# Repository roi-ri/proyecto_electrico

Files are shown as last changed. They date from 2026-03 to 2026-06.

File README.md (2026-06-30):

# Proyecto Eléctrico - Ciclador de Baterías

Repositorio integral del proyecto de diseño, construcción y validación de un
ciclador de baterías de propósito múltiple. El proyecto reúne el hardware de
potencia y medición, el firmware de control, el protocolo de comunicación y una
aplicación de escritorio para operar pruebas, visualizar telemetría y exportar
resultados.

## Descripción general

El sistema está orientado a ejecutar pruebas controladas de carga, descarga y
ciclado sobre baterías. La arquitectura combina una PCB dedicada, un ESP32 como
unidad de control y adquisición, sensores de corriente y tensión, y la
aplicación `batView` para supervisar el proceso desde una computadora.

Los objetivos principales del repositorio son:

- Centralizar la documentación técnica y administrativa del proyecto.
- Mantener el diseño eléctrico y los archivos de fabricación de la PCB.
- Versionar el firmware encargado del control y la comunicación.
- Desarrollar la aplicación de escritorio para operación, monitoreo y
  exportación de datos.
- Conservar cronogramas, bitácoras y propuestas como evidencia del avance.

## Componentes del sistema

| Componente | Ubicación | Descripción |
|---|---|---|
| Aplicación de escritorio | `batView/` | Interfaz en C++/wxWidgets para controlar pruebas vía USB/UART, graficar telemetría y exportar resultados. |
| Firmware/control | `code/` | Código en C para control PI, monitoreo de carga/descarga, límites de tensión y comunicación con la PC. |
| PCB | `PCB/` | Proyecto KiCad con esquemático, layout, huellas, símbolos, modelos 3D, salidas e imágenes del diseño. |
| Propuesta | `propuesta/` | Descripción inicial del ciclador, diagramas y documentos de diseño por área. |
| Cronograma | `cronograma/` | Plan de trabajo semanal del proyecto. |
| Bitácoras | `bitácora/` | Registro individual de avances, decisiones y actividades. |

## Estructura del repositorio

```text
proyecto_electrico/
|
├── README.md                         documentación principal del repositorio
├── LICENSE                           licencia MIT del proyecto
├── .gitignore                        reglas generales de archivos ignorados
├── .gitmodules                       submódulos utilizados por el repositorio
|
├── batView/                          aplicación de escritorio del proyecto
│   ├── README.md                     guía técnica de batView
│   ├── CMakeLists.txt                configuración de compilación y pruebas
│   ├── build_app.sh                  build completo para macOS/Linux
│   ├── build_app.ps1                 build completo para Windows
│   ├── install_macos.sh              instalación y empaquetado en macOS
│   ├── install_linux.sh              instalación y empaquetado en Linux
│   ├── install_windows.ps1           instalación y empaquetado en Windows
│   ├── src/                          código fuente de la aplicación
│   ├── tests/                        pruebas unitarias
│   ├── docs/                         documentación de arquitectura e instalación
│   ├── examples/                     firmware de prueba para ESP32
│   ├── scripts/                      automatización de build
│   └── assets/                       iconos e imágenes de la aplicación
|
├── code/                             firmware y control embebido
│   ├── include/                      encabezados del firmware
│   └── src/                          implementaciones en C
|
├── PCB/                              diseño electrónico en KiCad
│   ├── README.md                     documentación de la PCB
│   ├── Proyecto.kicad_pro            archivo principal del proyecto KiCad
│   ├── Proyecto.kicad_sch            esquemático eléctrico
│   ├── Proyecto.kicad_pcb            layout de la PCB
│   ├── symbols/                      símbolos personalizados
│   ├── footprints/                   huellas personalizadas
│   ├── 3dmodels/                     modelos 3D de componentes
│   ├── outputs/                      salidas generadas del diseño
│   └── Imagenes/                     vistas y capturas del diseño
|
├── propuesta/                        propuesta y documentos iniciales
│   ├── propuesta.md                  planteamiento general
│   ├── images/                       diagramas e imágenes de apoyo
│   ├── programa_sw/                  documentación del software
│   ├── protocolo_comunicacion/       documentación del protocolo
│   └── ciclador/                     documentación del ciclador
|
├── cronograma/                       planificación temporal
│   └── cronograma.md                 cronograma semanal
|
└── bitácora/                         bitácoras individuales del equipo
    ├── Brandon.md
    ├── Edu.md
    ├── Jose.md
    ├── Luis.md
    └── Rodrigo.md
```

## Flujo de trabajo del sistema

1. La PCB integra las etapas de potencia, acondicionamiento, sensado y conexión
   con el ESP32.
2. El firmware del ESP32 ejecuta el control de carga/descarga, monitorea
   variables eléctricas y aplica límites de seguridad.
3. La PC se comunica con el ESP32 mediante USB/UART usando tramas de protocolo
   definidas para conexión, configuración, carga, descarga, ciclado y paro.
4. `batView` envía comandos, recibe telemetría, muestra el estado de la prueba,
   grafica mediciones y exporta datos para análisis posterior.

## Protocolo de comunicación

La aplicación y el ESP32 intercambian mensajes de texto con prefijo `#`. Entre
las tramas principales utilizadas por `batView` se encuentran:

- `#CONNECTION`
- `#Battery,<BatteryNameID>,<V@max>,<V@min>,<Amax>`
- `#CICLE,0,0`
- `#CICLE,1,<numeroCiclos>`
- `#LOAD,<0-100>`
- `#UNLOAD,<0-100>`
- `#STOP`
- `#DATA,<tensión>,<corriente>,<timestamp>`

La documentación detallada del protocolo y del flujo de la aplicación se
encuentra en [`batView/README.md`](batView/README.md) y en
[`propuesta/protocolo_comunicacion/`](propuesta/protocolo_comunicacion/).

## Requisitos principales

### Software de escritorio

Para compilar y ejecutar `batView` se requiere, según el sistema operativo:

- CMake.
- Compilador C++ compatible.
- wxWidgets.
- Python 3 y dependencias de empaquetado/exportación.
- Git.

Guías específicas:

- [Instalación en macOS](batView/docs/INSTALL_MACOS.md)
- [Instalación en Linux](batView/docs/INSTALL_LINUX.md)
- [Instalación en Windows](batView/docs/INSTALL_WINDOWS.md)

### Diseño electrónico

Para abrir o modificar la PCB se recomienda:

- KiCad.
- Librerías locales incluidas en `PCB/symbols/`, `PCB/footprints/` y
  `PCB/3dmodels/`.

### Firmware

Para trabajar con el código embebido se recomienda contar con:

- Toolchain compatible con ESP32 o entorno equivalente.
- Acceso al puerto USB/UART del microcontrolador.
- Instrumentación básica para validar tensión, corriente y polaridad antes de
  conectar baterías reales.

## Puesta en marcha rápida

1. Clonar el repositorio:

```bash
git clone <URL_DEL_REPOSITORIO>
cd proyecto_electrico
```

2. Revisar la documentación de la PCB:

```bash
open PCB/README.md
```

3. Entrar a la aplicación de escritorio:

```bash
cd batView
```

4. Ejecutar el instalador correspondiente al sistema:

```bash
./install_macos.sh
```

En Linux:

```bash
./install_linux.sh
```

En Windows:

```powershell
powershell -ExecutionPolicy Bypass -File .\install_windows.ps1
```

## Documentación recomendada

- [`batView/README.md`](batView/README.md): guía principal de la aplicación,
  arquitectura, protocolo, build, pruebas y exportación.
- [`PCB/README.md`](PCB/README.md): descripción de la PCB, conectores, sensores,
  capas y recomendaciones de conexión.
- [`propuesta/propuesta.md`](propuesta/propuesta.md): planteamiento general del
  proyecto.
- [`cronograma/cronograma.md`](cronograma/cronograma.md): actividades planeadas
  por semana.
- [`bitácora/`](bitácora/): seguimiento individual del avance del equipo.

## Estado del proyecto

El repositorio contiene una base funcional y documentada para el desarrollo del
ciclador:

- Aplicación `batView` con conexión serial, flujo guiado de pruebas, gráficas y
  exportación.
- Proyecto KiCad de PCB con documentación visual y descripción de conectores.
- Código de control con módulos separados para comunicación, control PI,
  monitoreo, límites de tensión y paro.
- Documentación académica de propuesta, cronograma y bitácoras.

## Buenas prácticas de uso

- Validar polaridad y niveles de tensión antes de conectar una batería real.
- Probar primero con fuentes limitadas en corriente o cargas controladas.
- Mantener separadas las salidas generadas localmente de los archivos fuente.
- Registrar cambios relevantes en las bitácoras correspondientes.
- Actualizar la documentación cuando se modifique el protocolo, la PCB o el
  flujo de operación de `batView`.

## Licencia

Este proyecto se distribuye bajo licencia MIT. Consulte [`LICENSE`](LICENSE)
para ver los términos completos.

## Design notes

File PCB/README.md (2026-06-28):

# PCB del ciclador de baterías

## Descripción general

En este directorio se encuentran los archivos de diseño de la PCB utilizada
para implementar el prototipo del ciclador de baterías.

La placa integra las etapas principales necesarias para realizar los procesos
de carga y descarga de la batería. Además, permite conectar el ESP32, los
sensores de corriente, el sensor de tensión, el convertidor de tensión externo,
la alimentación principal y la batería.

El diseño fue realizado en KiCad y utiliza cuatro capas de cobre:

- `F.Cu`: capa superior.
- `In1.Cu`: primera capa interna.
- `In2.Cu`: segunda capa interna.
- `B.Cu`: capa inferior.

Los archivos principales del proyecto son:

- `Proyecto.kicad_pro`: archivo principal del proyecto de KiCad.
- `Proyecto.kicad_sch`: esquemático eléctrico del circuito.
- `Proyecto.kicad_pcb`: diseño físico de la PCB.
- `symbols/`: símbolos personalizados utilizados en el esquemático.
- `footprints/`: huellas personalizadas utilizadas en la PCB.
- `3dmodels/`: modelos tridimensionales de los componentes.
- `Imagenes/`: imágenes de las capas y vistas tridimensionales de la PCB.

## Distribución general de la PCB

La PCB está organizada para separar las etapas de control, medición y potencia.

En la parte central de la placa se ubica el ESP32, el cual se encarga de
ejecutar el sistema de control. En el lado derecho se encuentran los
transistores de potencia, los disipadores, los inductores y las terminales
relacionadas con la batería y los sensores. En el lado izquierdo se ubican las
entradas de alimentación, las señales de control y las conexiones asociadas al
convertidor externo de tensión.

## Vista superior de la PCB

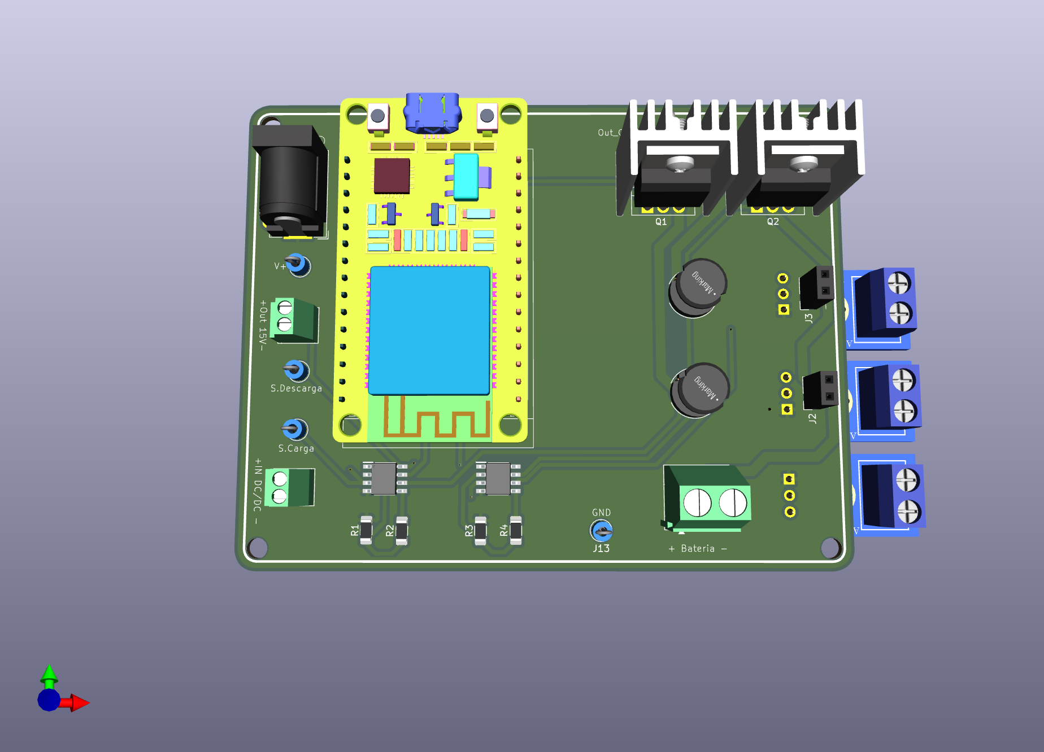
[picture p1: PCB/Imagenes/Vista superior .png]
Vista superior de la PCB


*Figura 1. Vista superior del prototipo de la PCB.*

En la vista superior se observa la distribución física de los componentes
principales del prototipo.

En el centro de la placa se encuentra el módulo ESP32. Este microcontrolador
recibe las señales de los sensores, ejecuta el algoritmo de control y genera
las señales necesarias para activar las etapas de carga y descarga.

En la parte superior derecha se encuentran los transistores de potencia `Q1` y
`Q2`. Estos transistores controlan el paso de corriente durante los procesos de
carga y descarga de la batería. Debido a que pueden disipar potencia durante su
funcionamiento, cada uno cuenta con un disipador de calor.

Debajo de los transistores se encuentran los inductores `L1` y `L2`. Estos
elementos forman parte de las trayectorias de potencia y permiten limitar las
variaciones bruscas de corriente.

En la parte inferior de la placa se observan los circuitos integrados `IC1` e
`IC2`, junto con las resistencias `R1`, `R2`, `R3` y `R4`. Estos componentes
forman las etapas de acondicionamiento y amplificación de las señales de
control provenientes del ESP32.

También se encuentran puntos de prueba para verificar señales importantes del
sistema:

- `S.Carga`: señal de control para la etapa de carga.
- `S.Descarga`: señal de control para la etapa de descarga.
- `Out_C.Ampli`: salida amplificada de la etapa de carga.
- `Out_D.Ampli`: salida amplificada de la etapa de descarga.
- `V+`: punto de medición de tensión positiva.
- `GND`: referencia común del circuito.

## Vista inferior de la PCB

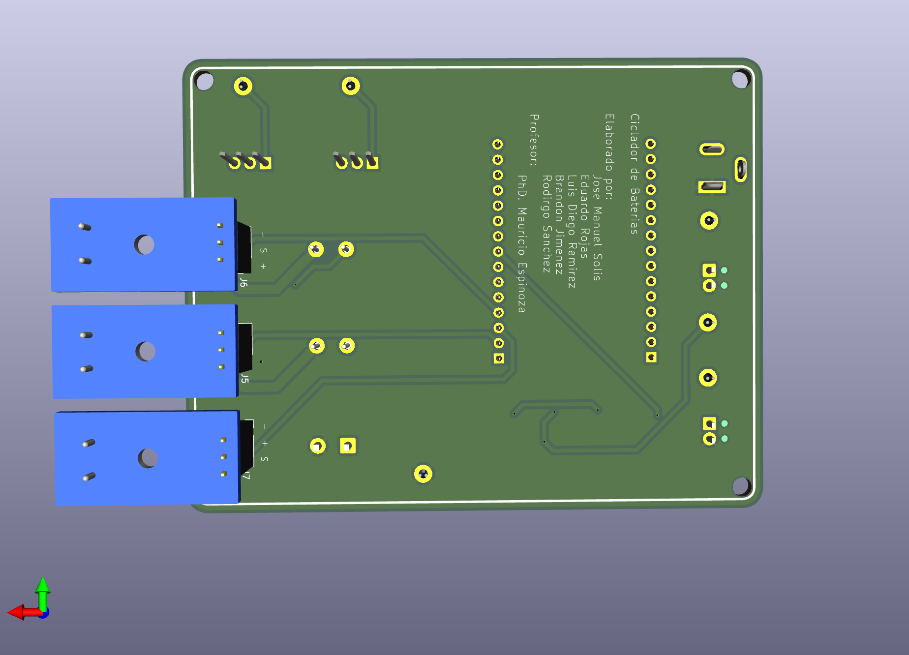
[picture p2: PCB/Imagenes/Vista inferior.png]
Vista inferior de la PCB


*Figura 2. Vista inferior del prototipo de la PCB.*

La vista inferior permite observar la parte posterior de la placa, donde se
aprecian las conexiones de los pines, los puntos de soldadura y las rutas que
comunican los diferentes bloques del circuito.

Esta vista es útil durante el ensamblaje porque permite revisar la orientación
de los conectores, verificar los puntos de soldadura y comprobar que no existan
cortocircuitos entre terminales cercanas.

También permite observar cómo se conectan físicamente los módulos externos a la
PCB, como el ESP32, los conectores de sensores, la alimentación y la batería.

## Conectores principales de la PCB

La placa cuenta con varios conectores que permiten integrar el prototipo final.

### Conector negro de alimentación principal

El conector negro ubicado en la esquina superior izquierda corresponde a la
alimentación principal de la PCB.

En este conector se conecta la fuente que alimenta el circuito completo. Esta
alimentación se utiliza para las etapas principales de potencia y para generar
las tensiones necesarias en el resto del sistema.

Antes de energizar la PCB se debe verificar la polaridad del conector y
confirmar con un multímetro que no exista cortocircuito entre la alimentación y
`GND`.

### Conectores verdes pequeños para el convertidor de 15 V a 5 V

En el lado izquierdo de la PCB se tienen dos conectores verdes pequeños. Estos
se utilizan para conectar un convertidor externo de tensión de `15 V` a `5 V`.

La idea es que la PCB entregue una tensión de `15 V` hacia el convertidor y que
el convertidor devuelva una tensión regulada de `5 V`. Esta tensión de `5 V` se
utiliza para alimentar los sensores del sistema.

Las conexiones se identifican como:

- `Out 15V`: salida de `15 V` desde la PCB hacia el convertidor.
- `IN DC/DC`: entrada de `5 V` desde el convertidor hacia la PCB.

### Terminal verde para la batería

La batería se conecta en la terminal verde identificada como `J4`, ubicada en
la parte inferior derecha de la PCB.

La polaridad está indicada en la serigrafía de la placa:

```text
+ Batería -
```

El terminal positivo de la batería debe conectarse al lado marcado con `+` y el
terminal negativo debe conectarse al lado marcado con `-`.

Antes de conectar una batería real se recomienda comprobar la polaridad con un
multímetro.

## Sensores del sistema

El prototipo utiliza sensores de corriente y un sensor de tensión. Estos
sensores permiten que el ESP32 conozca el estado eléctrico del circuito y pueda
calcular la acción de control correspondiente.

### Sensores de corriente

Los sensores de corriente se conectan abriendo la trayectoria de potencia. Para
esto se utilizan las terminales negras ubicadas en la parte superior de los
módulos de sensor.

La corriente que se desea medir debe pasar a través del sensor. Por eso, el
sensor de corriente se conecta en serie con la trayectoria de carga o descarga.

Cada sensor de corriente requiere:

- Alimentación de `5 V`.
- Conexión a `GND`.
- Conexión de la señal analógica hacia el ESP32.
- Conexión en serie con la trayectoria de corriente que se desea medir.

En el prototipo se utilizan sensores independientes para medir la corriente de
carga y la corriente de descarga.

### Sensor de tensión

El sensor de tensión se conecta directamente en paralelo con la batería. A
diferencia del sensor de corriente, no es necesario abrir la trayectoria de
potencia.

El sensor de tensión mide la diferencia de potencial entre los terminales de la
batería y entrega una señal proporcional al ESP32.

La salida del sensor debe mantenerse dentro del rango permitido por el ESP32,
es decir, entre `0 V` y `3.3 V`.

## Conexión general del prototipo final

El funcionamiento general del sistema es el siguiente:

1. La fuente principal alimenta la PCB mediante el conector negro.
2. La PCB entrega `15 V` hacia el convertidor externo.
3. El convertidor genera `5 V` para alimentar los sensores.
4. El ESP32 genera las señales `S.Carga` y `S.Descarga`.
5. Las señales del ESP32 pasan por las etapas de amplificación.
6. Las etapas amplificadas accionan los transistores de potencia.
7. Los inductores limitan las variaciones bruscas de corriente.
8. Los sensores de corriente miden la corriente de carga y descarga.
9. El sensor de tensión mide la tensión directamente en la batería.
10. Las señales medidas regresan al ESP32 para cerrar el lazo de control.

## Capa superior de cobre

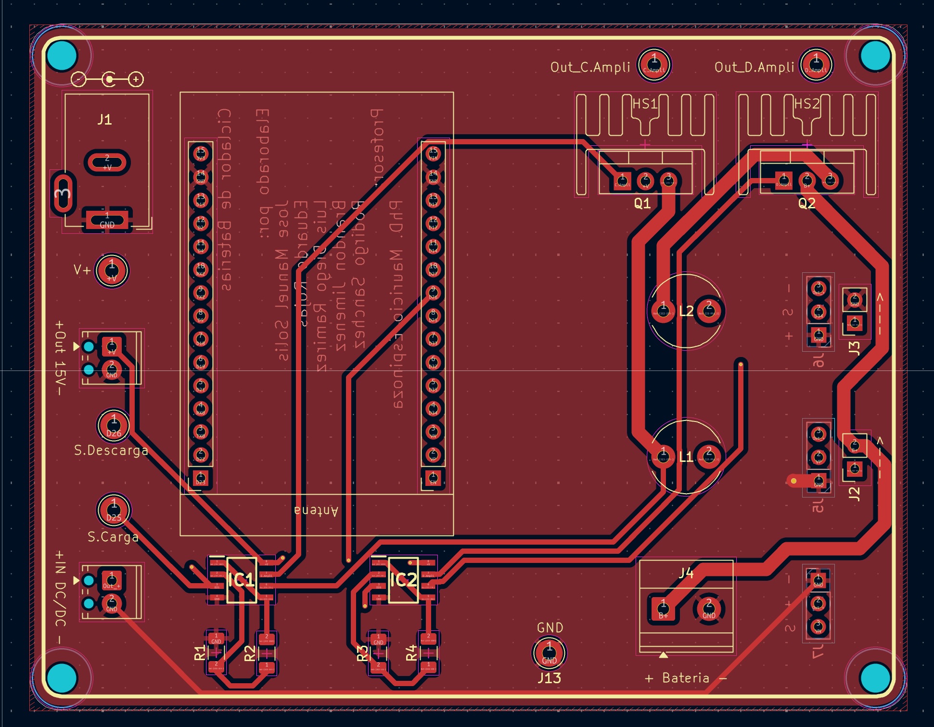
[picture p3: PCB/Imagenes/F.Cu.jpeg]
Capa superior de cobre


*Figura 7. Capa superior de cobre `F.Cu`.*

La capa superior contiene parte del enrutamiento principal de la PCB.

En esta imagen se observan las pistas que conectan el ESP32 con las etapas de
control, las etapas de amplificación con los transistores y las trayectorias de
potencia hacia los inductores y conectores externos.

Las pistas de mayor ancho corresponden a trayectorias donde puede circular una
corriente más alta. Las pistas más delgadas corresponden principalmente a
señales de control, medición y comunicación entre bloques.

## Primera capa interna

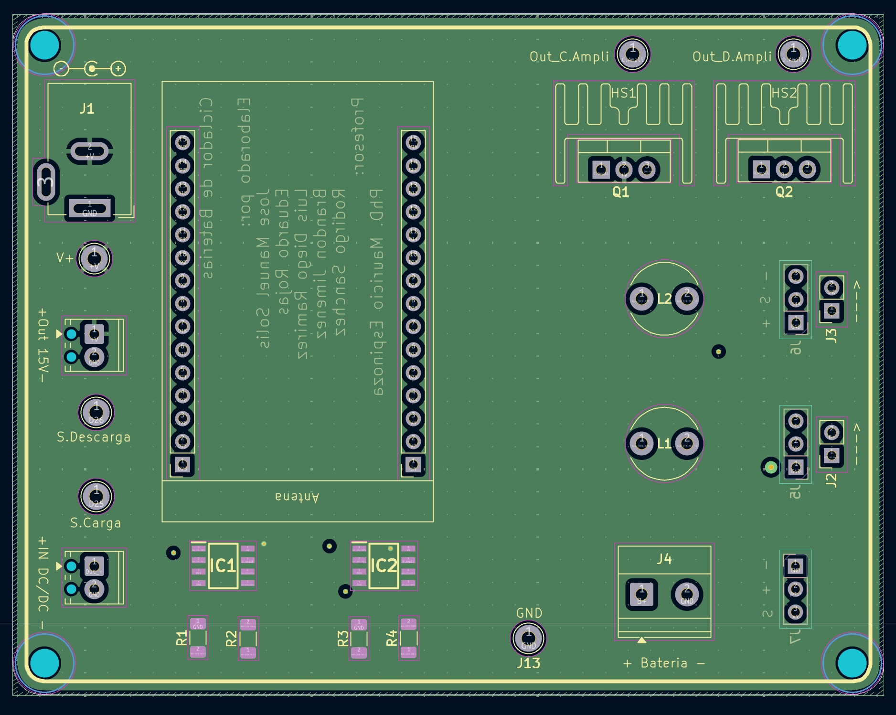
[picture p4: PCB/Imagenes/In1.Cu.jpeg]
Primera capa interna


*Figura 8. Primera capa interna `In1.Cu`.*

La primera capa interna corresponde a una zona de cobre utilizada para mejorar
la distribución eléctrica dentro de la PCB.

Esta capa ayuda a reducir la impedancia de las conexiones internas y permite
tener una referencia más uniforme para diferentes secciones del circuito.

También contribuye a separar las señales de control de las trayectorias de
potencia.

## Segunda capa interna

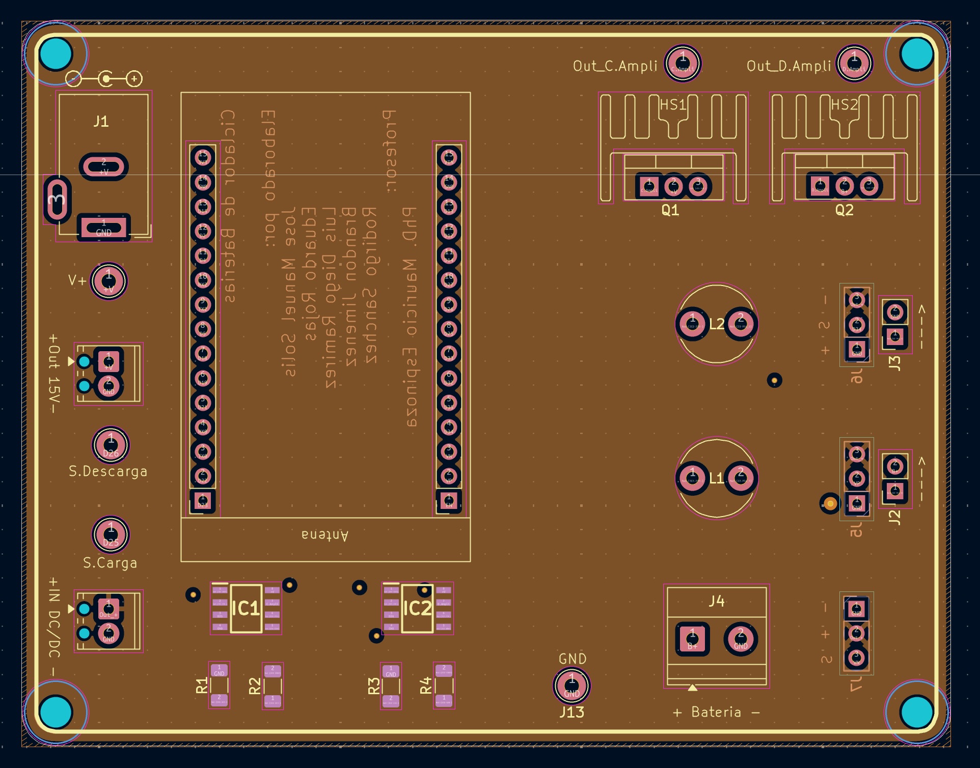
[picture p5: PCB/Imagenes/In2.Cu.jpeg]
Segunda capa interna


*Figura 9. Segunda capa interna `In2.Cu`.*

La segunda capa interna complementa la distribución de la alimentación y de las
referencias eléctricas del circuito.

Al utilizar una PCB de cuatro capas, se facilita la conexión entre los
componentes y se mejora la organización de las rutas internas. Esto permite
tener un diseño más limpio y con menor interferencia entre las señales de
potencia y las señales del ESP32.

## Capa inferior de cobre

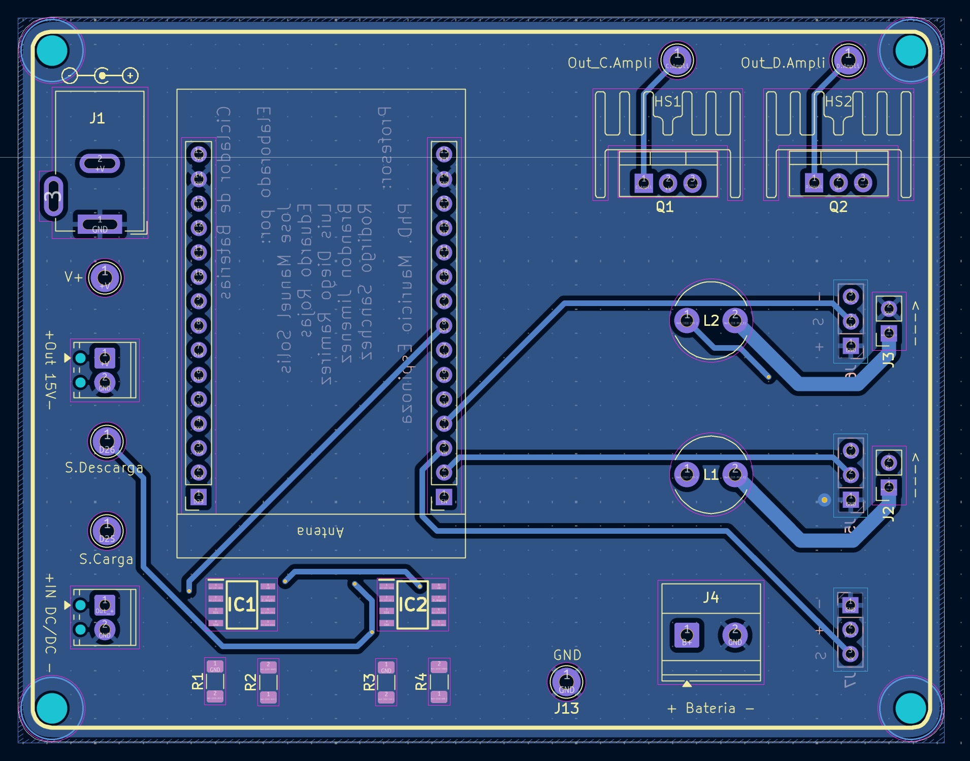
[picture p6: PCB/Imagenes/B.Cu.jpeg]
Capa inferior de cobre


*Figura 10. Capa inferior de cobre `B.Cu`.*

La capa inferior completa las conexiones que no se realizan en la capa
superior.

En esta imagen se observan rutas entre el ESP32, los circuitos integrados, los
transistores, los inductores, los conectores de sensores y la terminal de la
batería.

La combinación de las cuatro capas permite distribuir mejor las conexiones,
mantener referencias eléctricas más estables y separar de mejor manera las
señales de control de las trayectorias de corriente.

## Secuencia recomendada de conexión

Para conectar el prototipo se recomienda seguir el siguiente orden:

1. Mantener la batería desconectada.
2. Conectar la fuente principal al conector negro de alimentación.
3. Verificar la tensión de entrada y la polaridad.
4. Conectar el convertidor externo de `15 V` a `5 V`.
5. Verificar que la salida del convertidor sea de `5 V`.
6. Conectar la alimentación de los sensores.
7. Conectar los sensores de corriente en serie usando las terminales negras.
8. Conectar el sensor de tensión directamente a los terminales de la batería.
9. Instalar el ESP32 en la PCB.
10. Verificar las señales `S.Carga` y `S.Descarga`.
11. Verificar las salidas `Out_C.Ampli` y `Out_D.Ampli`.
12. Conectar la batería respetando la polaridad indicada en `J4`.
13. Iniciar las pruebas con corriente limitada.

## Uso de los archivos de KiCad

Para abrir el proyecto completo se debe utilizar el archivo:

```text
Proyecto.kicad_pro
```

Este archivo permite abrir el diseño completo en KiCad.

El esquemático eléctrico se encuentra en:

```text
Proyecto.kicad_sch
```

El diseño físico de la PCB se encuentra en:

```text
Proyecto.kicad_pcb
```

Las carpetas `symbols`, `footprints` y `3dmodels` deben mantenerse junto con el
proyecto, ya que contienen elementos utilizados por el diseño.

## Advertencia

Este diseño corresponde a un prototipo académico. Antes de conectar una batería
real se deben revisar cuidadosamente las conexiones, la polaridad, los niveles
de tensión, las corrientes máximas y el funcionamiento del sistema de control.

Una conexión incorrecta puede dañar la PCB, el ESP32, los sensores, los
transistores o la batería.

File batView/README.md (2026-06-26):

# batView

Aplicación de escritorio en C++ para controlar pruebas de baterías sobre un ESP32 vía USB/UART.
El proyecto combina wxWidgets para la interfaz, una capa de servicios para la lógica de protocolo y adaptadores de infraestructura para serial, logging y exportación.

## Resumen
batView está orientado a ejecutar y supervisar pruebas de baterías desde una interfaz de escritorio, con telemetría recibida en tiempo real desde el ESP32 y exportación de los resultados en formatos útiles para análisis y trazabilidad.

## Características principales
- Conexión serial real a ESP32 en macOS/Linux mediante backend POSIX.
- Handshake de conexión con reintento automático para boards que reinician al abrir el puerto.
- Flujo operativo guiado para conectar, seleccionar batería, elegir función, iniciar carga, descarga o ciclado y detener con `#STOP`.
- Recepción de telemetría `#DATA`.
- Registro de tráfico ESP32 <-> PC en la UI.
- Exportación de mediciones a CSV.
- Exportación de mediciones a MAT y XLSX.
- Exportación de gráficas a CSV, MAT, XLSX y PNG.
- Panel de gráficas con renderizado real y resumen del último punto capturado.
- Sketches de prueba para Arduino IDE y PlatformIO.

## Estructura del proyecto
```text
batView/
│
├── README.md                         guia principal del proyecto
├── CMakeLists.txt                    configuracion de build, empaquetado y tests
├── build_app.sh                      build full en macOS/Linux
├── build_app.ps1                     build full en Windows
├── install_macos.sh                  prepara herramientas y empaqueta en macOS
├── install_linux.sh                  prepara herramientas y empaqueta en Linux
├── install_windows.ps1               prepara herramientas y empaqueta en Windows
│
├── src/                              codigo fuente de la app
│   ├── main.cpp                      entrada para modo consola/stub
│   ├── app/                          composicion de servicios de aplicacion
│   │   ├── AppController.h
│   │   └── AppController.cpp
│   ├── core/                         protocolo y logica de negocio
│   │   ├── protocol/                 codec, parser y tipos de mensajes seriales
│   │   └── services/                 conexion, adquisicion, exportacion y sesiones
│   ├── infrastructure/               adaptadores concretos
│   │   ├── csv/                      exportacion CSV
│   │   ├── logging/                  logger de consola
│   │   ├── python/                   motor embebido para graficas/exportacion
│   │   └── serial/                   puertos seriales POSIX, Windows y stub
│   ├── models/                       estructuras de mediciones
│   └── ui/                           interfaz wxWidgets
│       ├── BatViewApp.h/.cpp         arranque grafico de la aplicacion
│       ├── dialogs/                  dialogos como exportacion
│       ├── frames/                   ventana principal y flujo guiado
│       ├── panels/                   paneles de conexion y graficas
│       └── viewmodels/               puente entre UI y servicios
│
├── assets/                           iconos e imagenes de la app
│   ├── BatView.png
│   └── batView.gif
│
├── docs/                             documentacion de uso, arquitectura e instalacion
│   ├── ARCHITECTURE.md               decisiones de arquitectura
│   ├── BUILD_INSTALLER.md            indice de instalacion y limpieza
│   ├── INSTALL_MACOS.md              instalacion en macOS
│   ├── INSTALL_LINUX.md              instalacion en Linux
│   ├── INSTALL_WINDOWS.md            instalacion en Windows
│   └── PROJECT_DOCUMENTATION.md      documentacion tecnica general
│
├── examples/                         firmware de prueba para ESP32
│   ├── arduino/                      sketch para Arduino IDE
│   └── platformio/                   proyecto PlatformIO
│
├── tests/                            pruebas unitarias de servicios
│   ├── AcquisitionServiceTest.cpp
│   ├── ConnectionServiceTest.cpp
│   ├── ExportServiceTest.cpp
│   └── PlotServiceTest.cpp
│
├── scripts/                          utilidades de build
│   └── build_app.py                  prepara runtime Python, compila y empaqueta
│
├── cmake/                            plantillas de empaquetado nativo
├── python/                           runtime Python embebido generado localmente
├── build-release/                    salida local de compilacion
├── dist/                             instaladores/paquetes generados
├── data/                             datos de sesion o salidas locales
└── logs/                             registros locales
```
## Arquitectura del código

- `src/app/`: punto de entrada y composición de la aplicación.
- `src/core/`: protocolo y lógica de negocio.
- `src/infrastructure/`: adaptadores para CSV, logging y serial.
- `src/models/`: entidades y estructuras de dominio.
- `src/ui/`: ventanas, paneles, diálogos y viewmodels.

## Protocolo soportado
### Comandos enviados por la aplicación

- `#CONNECTION`
- `#Battery,<BatteryNameID>,<V@max>,<V@min>,<Amax>`
- `#CICLE,0,0`
- `#CICLE,1,<numeroCiclos>`
- `#LOAD,<0-100>`
- `#UNLOAD,<0-100>`
- `#STOP`

### Respuestas esperadas del ESP32
- `#ACK,CONNECTION` o `#ACK,CONECTION`
- `#ACK,Battery`
- `#ACK,CICLE`
- `#ACK,LOAD`
- `#ACK,UNLOAD`
- `#ACK,STOP`
- `#STATUS,<modo>,<detalle>`
- `#ERROR,<codigo>,<mensaje>`
- `#DATA,<tension>,<corriente>,<timestamp>`
- `#DATA,<tension>,<corriente>,<timestamp>,<estado>,<ciclos>`

### Origen de los datos de telemetría
Los datos que la aplicación grafica y exporta provienen del ESP32 a través de las tramas `#DATA`.

- `tension`: valor enviado por el ESP32.
- `corriente`: valor enviado por el ESP32.
- `timestamp`: valor enviado por el ESP32 en milisegundos.
- `estado`: valor enviado por el ESP32 cuando se usa la variante larga.
- `ciclos`: valor enviado por el ESP32 cuando se usa la variante larga.

La aplicación no fabrica esos valores. Lo único que hace en la gráfica es convertir `timestamp` de milisegundos a segundos para mostrar un eje de tiempo más legible. El dato original almacenado sigue siendo el que envía el ESP32.

## Build y ejecución multiplataforma
If you want to install batView, open the guide for your system:

- [macOS install guide](docs/INSTALL_MACOS.md)
- [Linux install guide](docs/INSTALL_LINUX.md)
- [Windows install guide](docs/INSTALL_WINDOWS.md)

Each guide has two clear cases:

- If nothing is installed yet.
- If everything needed is already installed.

Use only the guide for your own computer.

| Your computer | Script to run |
|---|---|
| Mac | `./install_macos.sh` |
| Linux | `./install_linux.sh` |
| Windows | `powershell -ExecutionPolicy Bypass -File .\install_windows.ps1` |

Do not run the other scripts. Each one is for a different operating system.

### What you need before installing
If you are not sure what to install first, use this checklist.

#### Mac
Install these once if they are not already installed:

1. Apple command line tools.
2. Homebrew.
3. These Homebrew packages: `cmake`, `wxwidgets`, `python`, `pkg-config`.

Step by step:

```bash
xcode-select --install
```

Then install Homebrew if needed:

```bash
/bin/bash -c "$(curl -fsSL https://raw.githubusercontent.com/Homebrew/install/HEAD/install.sh)"
```

Then install the required packages:

```bash
brew install cmake wxwidgets python pkg-config
```

#### Linux
Install these packages:

1. CMake.
2. A C++ compiler and build tools.
3. wxWidgets development files.
4. GTK development files.
5. Python 3, Python headers, and pip.

Step by step on Ubuntu or Debian:

```bash
sudo apt update
sudo apt install -y cmake g++ make pkg-config libwxgtk3.2-dev libgtk-3-dev python3 python3-dev python3-pip
```

Step by step on Fedora:

```bash
sudo dnf install -y cmake gcc-c++ make pkgconf-pkg-config wxGTK-devel gtk3-devel python3 python3-devel python3-pip rpm-build zip
```

Step by step on Arch Linux:

```bash
sudo pacman -S --needed cmake gcc make pkgconf wxwidgets-gtk3 gtk3 python python-pip zip
```

#### Windows
Install these programs:

1. Visual Studio 2022 with the `Desktop development with C++` workload.
2. CMake.
3. Python 3.
4. wxWidgets compatible with your compiler.
5. Git.
6. NSIS if you want an installer package.

Step by step:

```powershell
winget --version
winget install --id Microsoft.VisualStudio.2022.BuildTools --exact --silent --accept-package-agreements --accept-source-agreements --override "--quiet --wait --add Microsoft.VisualStudio.Workload.VCTools --includeRecommended"
winget install --id Kitware.CMake --exact --silent --accept-package-agreements --accept-source-agreements
winget install --id Python.Python.3.13 --exact --silent --accept-package-agreements --accept-source-agreements
winget install --id Git.Git --exact --silent --accept-package-agreements --accept-source-agreements
winget install --id NSIS.NSIS --exact --silent --accept-package-agreements --accept-source-agreements
```

Then run the project installer:

```powershell
cd C:\path\to\proyecto_electrico\batView
powershell -ExecutionPolicy Bypass -File .\install_windows.ps1
```

### If the tools are already installed
Use the same script, but add the skip-deps option.

```bash
./install_macos.sh --skip-deps
./install_linux.sh --skip-deps
```

```powershell
powershell -ExecutionPolicy Bypass -File .\install_windows.ps1 -SkipDeps
```

### Limpiar artefactos generados
Si quieres borrar lo que generan los scripts sin tocar el codigo fuente:

```bash
./build_app.sh --clean
```

En Windows:

```powershell
powershell -ExecutionPolicy Bypass -File .\build_app.ps1 --clean
```

Esto elimina `build-release/`, `dist/`, `python/runtime/` y la copia de `batView.app` en el Desktop.

### Para dejar la app fuera del repo
Después de compilar:

- macOS: el script copia `batView.app` al `Desktop`.
- Linux: el script crea un lanzador `batView.desktop` en el `Desktop`.
- Windows: el script crea un acceso directo `batView.lnk` en el `Desktop`.

### App wxWidgets
Esta sección es la ruta manual avanzada. Solo úsala si quieres compilar paso a paso sin el script automático.

#### macOS
```bash
cmake -S . -B build-release -DBATVIEW_ENABLE_WX=ON -DCMAKE_BUILD_TYPE=Release
cmake --build build-release --config Release
open build-release/batView.app
```

#### Linux
```bash
cmake -S . -B build-release -DBATVIEW_ENABLE_WX=ON -DCMAKE_BUILD_TYPE=Release
cmake --build build-release --config Release
./build-release/batView
```

##### Notas para Ubuntu
Si clonas o copias el repo desde otro sistema operativo, no reutilices el mismo `build-release` entre máquinas (por ejemplo macOS -> Ubuntu), porque CMake guarda rutas absolutas en cache.

Instala dependencias (Ubuntu 24.04):
```bash
sudo apt update
sudo apt install -y cmake g++ make pkg-config libwxgtk3.2-dev libgtk-3-dev
```

Si `find_package(wxWidgets)` falla, también puedes instalar:
```bash
sudo apt install -y wx3.2-headers wx-common
```

Reconfigura desde cero en Ubuntu:
```bash
rm -rf build-release
cmake -S . -B build-release -DBATVIEW_ENABLE_WX=ON -DCMAKE_BUILD_TYPE=Release
cmake --build build-release -j"$(nproc)"
./build-release/batView
```

Errores comunes:
- `CMakeCache.txt directory is different`: elimina `build-release` y vuelve a configurar.
- `Could NOT find wxWidgets`: instala los paquetes de desarrollo de wxWidgets (`libwxgtk3.2-dev`).

#### Windows
```powershell
cmake -S . -B build-release -DBATVIEW_ENABLE_WX=ON -DCMAKE_BUILD_TYPE=Release
cmake --build build-release --config Release
.\build-release\Release\batView.exe
```

### Empaquetado manual
Comando recomendado para generar un paquete local portable:

```bash
cmake -S . -B build-release -DBATVIEW_ENABLE_WX=ON -DCMAKE_BUILD_TYPE=Release -DBATVIEW_PACKAGE_FORMAT=PORTABLE
cmake --build build-release --config Release --target package
```

Esto genera artefactos dentro de `dist/` usando un formato portable y estable por plataforma:
- macOS: `.zip`
- Windows: `.zip`
- Linux: `.tar.gz`

Si necesitas un instalador nativo en vez del paquete portable, reconfigura con:
```bash
cmake -S . -B build-release -DBATVIEW_ENABLE_WX=ON -DCMAKE_BUILD_TYPE=Release -DBATVIEW_PACKAGE_FORMAT=NATIVE
cmake --build build-release --config Release --target package
```

Notas:
- En macOS, el formato nativo usa `DragNDrop` (`.dmg`) y puede fallar en algunos entornos locales.
- En Linux, el formato nativo intenta generar un `.deb`.
- En Windows, el formato nativo intenta generar un instalador `NSIS`.

### Suite de tests
```bash
cmake -S . -B build-tests -DBATVIEW_BUILD_TESTS=ON
cmake --build build-tests --config Release
ctest --test-dir build-tests --output-on-failure
```

## Artefactos
- El paquete generado queda fuera del directorio de build, en `dist/`.

## Ejemplos para ESP32
- [examples/arduino/esp32_batview_test](./examples/arduino/esp32_batview_test/README.md)
- [examples/platformio/esp32_batview_test](./examples/platformio/esp32_batview_test/README.md)

## Documentación
- [docs/PROJECT_DOCUMENTATION.md](./docs/PROJECT_DOCUMENTATION.md)
- [docs/ARCHITECTURE.md](./docs/ARCHITECTURE.md)
- [docs/BUILD_INSTALLER.md](./docs/BUILD_INSTALLER.md)

## Estado del proyecto
El proyecto ya cuenta con una base funcional sólida para pruebas reales con ESP32.

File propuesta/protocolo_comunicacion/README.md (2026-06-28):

# Propuesta para protocolo de comunicación 

## Objetivo del sistema

Desarrollar un sistema de control basado en un microcontrolador que permita la interacción con una computadora mediante un protocolo de comunicación definido, facilitando el intercambio de información y el control de dispositivos del sistema, de manera que se establezca una comunicación eficiente entre el usuario y el controlador, que permita:

- Recibir y decodificar comandos enviados desde una interfaz de usuario en la computadora mediante el protocolo de comunicación establecido.  
- Procesar las solicitudes recibidas para ejecutar acciones sobre sensores o dispositivos conectados al sistema.  
- Adquirir datos provenientes de sensores o del estado interno del sistema para su transmisión hacia la computadora.  
- Enviar información de retorno hacia la computadora, incluyendo estados del sistema, confirmación de comandos ejecutados y datos adquiridos.  
- Organizar el intercambio de información mediante una estructura de mensajes o tramas que garantice la correcta interpretación de los datos transmitidos.

## Alcances

El sistema contempla el desarrollo de un controlador basado en un microcontrolador y un protocolo de comunicación definido para la interacción con una computadora, que pueda realizar lo siguiente:
- Comunicación bidireccional entre la computadora y el controlador mediante un protocolo de comunicación previamente definido.
- Recepción y procesamiento de comandos provenientes de una interfaz de usuario en la computadora.
- Interpretación de los datos recibidos para ejecutar acciones específicas dentro del sistema de control.
- Envío de información desde el controlador hacia la computadora, incluyendo estados del sistema, confirmación de comandos y datos adquiridos de sensores.
- Integración de sensores o dispositivos externos que permitan la adquisición de información relevante para el funcionamiento del sistema.
- Implementación de un esquema de control que permita ejecutar las acciones solicitadas por el usuario de manera estructurada.
- Organización del intercambio de datos mediante una estructura de mensajes que facilite la interpretación y manejo de la información transmitida.
- Visualización en la computadora de los datos enviados por el controlador para el monitoreo del sistema.

## Limitaciones

En esta etapa no se contempla:
- Desarrollo o modificación del hardware asociado a los sensores o dispositivos que interactúan con el controlador.
- Implementación de múltiples protocolos de comunicación distintos al protocolo definido para el intercambio de datos entre la computadora y el microcontrolador.
- Ontegración con plataformas industriales de automatización, sistemas SCADA o plataformas industriales para control en tiempo real.
- Implementación de mecanismos avanzados de seguridad, cifrado o autentificación en la comunicación de datos.
- Manejo de grandes volúmenes de datos o transmisión de información de alta velocidad más allá de las capacidades del microcontrolador y del medio de comunicación utilizado,
- Escalabilidad hacia sistemas distribuidos con múltiples controladores o redes complejas de dispositivos.
- Certificación bajo normativas industriales o de seguridad específicas para aplicaciones críticas.

## Posibles protocolos de comunicación

### Protocolo UART
UART es un protocolo de comunicación seria asíncrono, lo que significa que no utiliza una señal de reloj compartida entre los dispositivos que se comunican. En su lugar, ambos dispositivos deben estar configurados con la misma velocidad de transmisión (baud rate) para interpretar correctamente los datos. La comunicación con UART se realiza generalmente utilizando dos líneas principales:

- **TX (Transmit)**: Línea de transmisión de datos.
- **RX (Receive)**: Línea de recepción de datos.

Cada dato transmitido se organiza en una trama que incluye:
- Bit de inicio (Start bit)
- Bits de datos (generalmente 8 bits)
- Bit opcional de paridad
- Bits de parada (Stop bits)

#### Ventajas
- Es full-duplex (puede transmitir y recibir datos al mismo tiempo).
- Implementación simple y ampliamente soportada por microcontroladores.
- Bajo número de pines requeridos.
- Fácil integración con interfaces de computadora.

#### Desventajas
- Velocidades menores comparadas con otros protocolos.
- No permite múltiples dispositivos en el mismo bus de forma directa.
- No posee sincronización por reloj, por lo que puede ser más susceptible a errores si las velocidades no coinciden.

Las velocidades típicas del protocolo UART van desde 9600 bps hasta varios Mbps, pero esto depende del hardware. Además UART no incluye mecanismos avanzados de verificación de errores, aunque puede emplear bits de paridad o implementaciones de software para verificar la integridad de los datos. UART necesita un convertidor para poder enviar los datos por USB.

### Protocolo SPI
SPI es un protocolo de comnicación serial sincrónico, desarrollado para permitir una comunicación rápida entre un dispositivo maestro (generalmente un microcontrolador) y uno o varios dispositivos esclavos. SPI utiliza cuatro líneas principales:
- **MOSI (Master Out Slave In)**: Datos enviados del maestro al esclavo.
- **MISO (Master In Slave Out)**: Datos enviados del esclavo al maestro.
- **SCLK (Serial Clock)**: Señal de reloj generada por el maestro,
- **CS/SS (Chip Select)**: Selección del dispositivo esclavo.

#### Ventajas
- Alta velocidad de transmisión.
- Es full-duplex (puede transmitir y recibir datos al mismo tiempo).
- Baja latencia en la transmisión de datos.

#### Desventajas
- Requiere más líneas físicas que otros protocolos.
- Cada dispositivo esclavo requiere una línea Chip Select adicional.
- No existe un estándar universal para la estructura de datos, por lo que depende de cada dispositivo.

El SPI puede alcanzar velocidades de decenas de Mbps, dependiendo del microcontrolador y del hardware utilizado. El protocolo no incluye verificación de errores integrada, por lo que se suele implementar CRC o verificación por software cuando la aplicación lo requiere. Este tampoco es compatible con USB, por lo que se necesita un convertidor SPI-USB.

### Protocolo I2C
I2C es un protocolo serial sincrónico diseñado para permitir la comunicación entre múltiples dispositivos utilizando únicamente dos líneas de comunicación:
- **SDA (Serial Data)**: Línea de datos.
- **SCL (Serial Clock)**: Línea de reloj.
A diferencia de SPI, I2C permite conectar múltiples dispositivos en el mismo bus, identificándolos mediante direcciones únicas.
#### Ventajas
- Solo requiere dos líneas para múltiples dispositivos.
- Permite comunicación multimaestro y multiesclavo.
- Amplio soporte en sensores, memorias y circuitos integrados.

#### Desventajas
- Velocidad mejor comparada con SPI.
- Mayor complejidad en la gestión del bus cuando hay muchos dispositivos.
- Distancias de comunicación relativamente cortas.

Las velocidades del I2C son variadas, ya que hay de 100kbps, 400 kbps, 1 Mbps hasta 3,4 Mbps y además este protocolo incluye mecanismos como ACK/NACK para confirmar recepción de datos y control de colisiones en sistemas multimaestro. El protocolo I2C no es compatible con usb, por lo que se necesita un adaptador I2C-USB.

## Propuesta inicial
Como propuesta inicial para el sistema de comunicación entre la computadora y el controlador se plantea la utilización del protocolo UART, debido a su simplicidad de implementación, amplia compatibilidad con microcontroladores y facilidad de integración con computadoras mediante interfaces USB.
La selección de este protocolo se fundamenta en que el sistema contempla la comunicación con un único dispositivo controlador, por lo que no es necesario implementar un bus que permita múltiples dispositivos conectados simultáneamente, como ocurre con protocolos como I2C o SPI. En este contexto, UART resulta adecuado al permitir una comunicación serial directa entre el microcontrolador y la computadora utilizando únicamente líneas de transmisión y recepción de datos, además de que UART es full-duplex, por lo que no habrá problemas de interrupción en el recibimiento o envío de datos si se desea hacer un cambio mientras la computadora recibe datos.
Adicionalmente, el uso de UART facilita el desarrollo y depuración del sistema, ya que permite visualizar y enviar datos de forma directa mediante herramientas de monitoreo serial disponibles en diferentes entornos de desarrollo o aplicaciones de comunicación serial en la computadora.
En cuanto a la interfaz física, el sistema utilizará la conexión USB disponible en la placa de desarrollo del ESP32, la cual permite establecer la comunicación con la computadora. Ya que en la placa que se utiliza el conector USB incorpora un convertidor USB-UART integrado, que actúa como intermediario entre el protocolo USB utilizado por la computadora y la comunicación serial UART del microcontrolador. Gracias a esto es posible generar simplificaciones y ahorro de costos ya que no es necesario implementar adaptadores externos adicionales, ya que la placa permite que la computadora reconozca el dispositivo como un puerto serial virtual.
De esta manera, el protocolo UART permitirá que el sistema:

- Reciba comandos enviados desde la computadora a través de la interfaz de usuario.
- Procese dichos comandos en el microcontrolador para ejecutar las acciones correspondientes en el sistema de control.
- Envíe información de retorno hacia la computadora, como estados del sistema, confirmación de comandos o datos adquiridos por los sensores.

### Sistema de control para filtrado y manejo de los datos.

La propuesta del sistema de control está orientado en los valores que se desean observar en la interfaz gráfica y que son de interés para el usuario, por lo que los datos son:

- Corriente de carga.
- Corriente de descarga.
- Tensión actual de la batería.
- Estado de la batería.

Además, debido al tipo de sensor utilizado para la medición de los valores, no se considera necesaria una etapa adicional de filtrado, ya que el tipo de sensor ofrece mediciones confiables y adecuadas para el sistema.

El sistema tendrá como función principal captar las señales de corriente y tensión, procesarlas en el controlador y organizarlas para su transmisión o visualización. Además según la operación se va a clasificar como corriente de carga o descarga según sea la opción que deseó el usuario.

- **Corriente de carga**: La corriente captada cuando se está en el proceso de carga de la batería.
- **Corriente de descarga**: La corriente obtenido cuando se está en el proceso de descarga de la batería.
- **Tensión de la batería**: Se mide la tensión de la batería en ambas situaciones si se está cargando o descargando.
- **Estado de la batería**: Si se encuentra en carga o descarga.

De esta manera el sistema entregará los datos en el siguiente formato:

| Corriente (de carga o de descarga) , Tensión de la batería , Estado de la batería|
|----------------------------------------------------------|

La corriente debido al diseño del circuito solo se va a estar leyendo de una parte del circuito, ya que la otra parte del circuito se va a encontrar en un abierto, es por esto que se envía solamente una corriente y si se encuentra cargando o descargando, ya que esta información es importante para saber en que estado se encuentra la batería, incluso en el ciclado saber si se encuentra en etapa de carga o de descarga. Para enviar el dato del estado de la batería, se utiliza el siguiente código:

- Carga: 1
- Descarga: 0

### Entradas y salidas

Las entradas que se van a tener en el ESP32 son 4, la entrada USB, en donde se van a recibir las solicitudes del usuario, las cuales las entrega a través de la interfaz, además de 3 entradas analógicas, provenientes de los 3 sensores, 2 de corriente y el sensor de tensión.

- Sensor de corriente 1: Entrada analógica
- Sensor de corriente 2: Entrada analógica
- Sensor de tensión: Entrada analógica

Mientras que para las salidas, se necesitan 3, las cuales 1 salida es el USB, en donde se van a enviar los datos a la computadora, y 2 salidas analógicas las cuales serán las señales de control enviadas a la PCB para que cargue o descargue la batería.

- Señal de control 1: Salida analógica
- Señal de control 2: Salida analógica

Estas salidas no necesitan de ningún convertidor, ya que la placa de desarrollo trae implementado algunas salidas que ya incorporan dentro este convertidor.

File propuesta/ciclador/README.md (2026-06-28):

# Propuesta del circuito ciclador

## Objetivo del circuito

El objetivo principal del proyecto es diseñar e implementar un circuito
ciclador capaz de cargar y descargar una batería mediante el control de la
corriente. Para ello, se utilizará una topología basada en inductores y
transistores de potencia, acompañada de un sistema de control que permita
regular adecuadamente los procesos de carga y descarga.

Los objetivos específicos del proyecto son los siguientes:

- Diseñar un circuito capaz de cargar y descargar una batería mediante el
  control de la corriente que circula a través del inductor.

- Seleccionar y dimensionar adecuadamente los componentes electrónicos que
  serán utilizados en el circuito.

- Diseñar un sistema de control basado en el comportamiento eléctrico del
  circuito, que permita regular la corriente de la batería de manera estable,
  suave y eficiente.

- Realizar simulaciones del circuito y del sistema de control en PLECS para
  validar su funcionamiento antes de la implementación física.

- Diseñar e implementar el circuito ciclador en una PCB utilizando KiCad.

- Ensamblar y soldar los componentes electrónicos sobre la PCB para construir
  el prototipo físico.

- Diseñar una interfaz que permita supervisar y configurar el funcionamiento
  del circuito desde una computadora.

- Estimar y cotizar el costo de los componentes electrónicos, la fabricación
  de la PCB y los demás elementos necesarios para construir el prototipo.

## Usuario objetivo

El sistema está orientado a estudiantes, investigadores y personal técnico de
laboratorio que requieran estudiar y analizar el comportamiento de baterías
mediante pruebas controladas de carga, descarga y ciclado.

El circuito permitirá conectar una batería y controlar sus procesos de carga y
descarga desde una computadora. Por medio de una interfaz de usuario, será
posible configurar los parámetros de la prueba, indicar el tipo de operación
que debe ejecutar el circuito y supervisar las principales variables eléctricas
de la batería.

Durante las primeras etapas del proyecto, el circuito podrá implementarse en
una placa de pruebas o en una placa perforada. Sin embargo, la implementación
final se realizará en una PCB diseñada específicamente para el sistema.

## Problema que resuelve

En entornos académicos y de laboratorio, el estudio y monitoreo de baterías
suele depender de cicladores comerciales, instrumentos independientes,
interfaces limitadas o procedimientos manuales para procesar los datos
obtenidos.

Esta situación puede generar las siguientes problemáticas:

- Los cicladores de baterías comerciales suelen tener un costo elevado.

- Algunos equipos solamente se encuentran disponibles en laboratorios
  específicos, lo que limita su acceso, movilidad y disponibilidad.

- Determinadas interfaces y herramientas de análisis requieren licencias
  costosas.

- Algunos sistemas comerciales ofrecen poca flexibilidad para configurar
  pruebas experimentales específicas.

- El uso de varios instrumentos independientes dificulta la integración de los
  procesos de carga, descarga, medición y almacenamiento de datos.

- El procesamiento manual de los datos aumenta el tiempo necesario para
  analizar el comportamiento de la batería y puede introducir errores.

El circuito propuesto busca ofrecer una alternativa de menor costo, orientada
al uso académico y experimental, que integre en un mismo sistema el control de
la corriente, la ejecución de los ciclos y la supervisión de las variables de
la batería.

## Contexto de uso

El sistema está diseñado para operar en entornos académicos, de investigación
o de laboratorio técnico, donde se realicen pruebas controladas de carga,
descarga y ciclado de baterías.

El circuito ciclador estará conectado a una computadora mediante un protocolo
de comunicación previamente definido. La computadora funcionará como interfaz
de supervisión y configuración, permitiendo establecer los parámetros de la
prueba, iniciar o detener el funcionamiento del sistema y observar las
variables eléctricas medidas.

El dispositivo deberá utilizarse bajo condiciones controladas y con una
batería compatible con las especificaciones eléctricas establecidas durante el
diseño.

En esta etapa, el proyecto no contempla aplicaciones industriales de alta
potencia ni su integración en sistemas críticos de producción. Su propósito
principal es facilitar la experimentación, el análisis y la validación del
comportamiento de baterías dentro de un laboratorio.

## Alcances

El proyecto contempla el diseño y la implementación de un circuito ciclador
con su respectivo sistema de control. Los principales alcances son los
siguientes:

- Diseñar el circuito eléctrico encargado de realizar los procesos de carga y
  descarga de la batería.

- Dimensionar los inductores, transistores, sensores, elementos de protección
  y demás componentes necesarios para el funcionamiento del sistema.

- Implementar un sistema de control robusto y eficiente que permita regular la
  corriente de la batería y corregir las perturbaciones que puedan presentarse
  durante la operación.

- Simular el comportamiento del circuito y del sistema de control antes de
  construir el prototipo físico.

- Diseñar una PCB capaz de soportar las corrientes y temperaturas esperadas
  durante múltiples ciclos de carga y descarga.

- Construir y ensamblar el prototipo físico mediante la soldadura de los
  componentes sobre la PCB.

- Implementar la comunicación entre el circuito y una computadora para
  configurar y supervisar las pruebas.

- Diseñar una carcasa que proteja la PCB y permita utilizar el dispositivo de
  forma segura dentro del laboratorio.

- Proporcionar protección ante pequeños golpes y ante las condiciones normales
  de manipulación del equipo.

- Obtener mediciones de las principales variables eléctricas de la batería,
  como corriente y tensión, durante los procesos de carga y descarga.

## Limitaciones del sistema

El sistema presenta las siguientes limitaciones:

- El diseño electrónico y el sistema de control se desarrollarán inicialmente
  para un modelo específico de batería.

- Aunque el circuito pueda probarse con baterías de características similares,
  no se puede garantizar su correcto funcionamiento fuera de las condiciones
  eléctricas para las cuales fue diseñado.

- El rango de tensión y corriente estará limitado por las características de
  los componentes seleccionados.

- La precisión de las mediciones dependerá de los sensores, convertidores y
  sistemas de adquisición utilizados.

- El comportamiento obtenido en la implementación física puede diferir de los
  resultados de simulación debido a pérdidas, tolerancias, ruido eléctrico,
  retardos y efectos térmicos.

- La calidad de las simulaciones dependerá de la precisión de los modelos de la
  batería y de los componentes electrónicos disponibles.

- Pueden presentarse problemas de convergencia o limitaciones durante las
  simulaciones realizadas en PLECS, PSpice o LTspice.

- La fabricación del prototipo dependerá de los plazos de producción y entrega
  de la PCB.

- Algunos componentes deberán adquirirse en el extranjero, lo que puede
  generar retrasos y costos adicionales.

- El prototipo no estará diseñado para aplicaciones industriales de alta
  potencia ni para sistemas críticos.

- El sistema deberá utilizarse dentro de un entorno controlado y bajo la
  supervisión de personal con conocimientos básicos de electrónica y manejo de
  baterías.

## [Diseño](Diseño/)

En esta sección se encuentra la propuesta de diseño utilizada para el ciclador junto con los calculos correspondientes que justifican el diseño y el sistema de control. 

## [Simulación](PLECS/)

En esta sección se tiene la simulación en Plecs del sistema de control y el modelo utilizado para las pruebas software in the loop con el que se simula el comportmaiento del circuito. 

## [PCB](PCB/)

En esta sección se encuentran los archivos de fabricación de la PCB.

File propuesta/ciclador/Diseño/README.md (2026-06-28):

## Diseño del circuito

La topología implementada se muestra en la **Figura 1**. En el lado izquierdo se encuentra el circuito encargado de la carga de la batería, mientras que en el lado derecho se ubica el circuito de descarga.

Ambas etapas presentan una estructura similar, debido a que en los dos casos se requiere controlar la corriente que circula hacia o desde la batería.

### 1. Etapa de carga

Al analizar la trayectoria de corriente del circuito de carga en sentido horario, se encuentran los siguientes elementos:

1. **Fuente de tensión:** proporciona la energía necesaria para cargar la batería.
2. **Transistor de potencia:** regula el paso de corriente mediante su conmutación.
3. **Inductor:** limita las variaciones bruscas de corriente y almacena energía.
4. **Batería:** recibe la corriente suministrada por el circuito de carga.

Desde el punto de vista del sistema de control, el transistor corresponde al **actuador**, ya que modifica la corriente del circuito según la señal de control aplicada.

### 2. Etapa de descarga

La etapa de descarga presenta una estructura semejante a la etapa de carga. En este caso, el transistor regula la corriente que sale de la batería, mientras que el inductor limita sus variaciones bruscas.

Debido a la relación entre la tensión aplicada al inductor y la variación de su corriente, es posible controlar la corriente de carga o descarga mediante la conmutación del transistor.

### 3. Acondicionamiento de la señal de control

La señal de control proveniente del ESP32 posee un rango de tensión entre **0 V y 3.3 V**.

Esta señal se introduce en un amplificador operacional configurado como **amplificador no inversor**, formado por resistencias de **1 kΩ** y **3.3 kΩ**. La ganancia del amplificador es:

$$
A_v = 1 + \frac{3\ \text{k}\Omega}{1\ \text{k}\Omega} = 4.3
$$

Por lo tanto, la tensión máxima de salida es aproximadamente:

$$
V_{\text{salida}} = 4.3(3.3\ \text{V}) = 14.2\ \text{V}
$$

### 4. Accionamiento del transistor

La amplificación es necesaria para proporcionar un nivel de tensión adecuado para el accionamiento del transistor.

Durante los procesos de carga y descarga, la tensión de control debe ser suficientemente alta con respecto al nodo ubicado entre el transistor y el inductor. Esto permite:

* Garantizar la correcta activación del transistor.
* Regular la corriente del circuito.
* Controlar la corriente que circula hacia o desde la batería.

## Diagrama del circuito

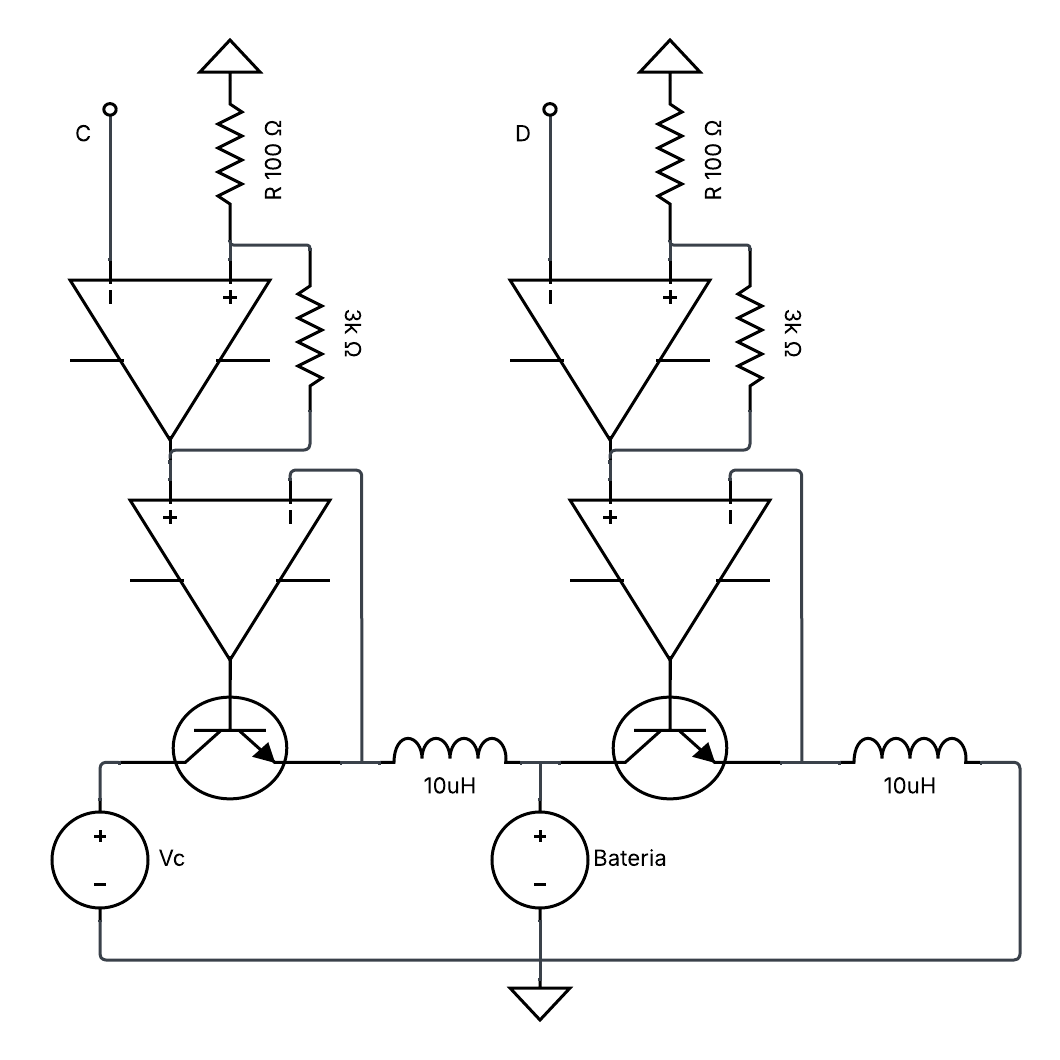
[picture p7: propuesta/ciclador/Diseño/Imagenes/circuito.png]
Circuito de carga y descarga de la batería


*Figura 1. Topología del circuito de carga y descarga de la batería.*

## Función de transferencia

### 1. Circuito de carga

Aplicando la **Ley de Voltajes de Kirchhoff** en sentido horario sobre el
circuito de carga, se obtiene:

$$
-v_C(t)+v_T(t)+v_L(t)+v_R(t)+v_B(t)=0
$$

La tensión en el inductor se expresa como:

$$
v_L(t)=L\frac{di_L(t)}{dt}
$$

Por otra parte, la caída de tensión en la resistencia parásita del circuito
está dada por:

$$
v_R(t)=R\cdot i_L(t)
$$

Sustituyendo ambas expresiones en la ecuación de tensiones:

$$
-v_C(t)+v_T(t)+L\frac{di_L(t)}{dt}
+R\cdot i_L(t)+v_B(t)=0
$$

Al reorganizar los términos:

$$
L\frac{di_L(t)}{dt}+R\cdot i_L(t) = v_C(t)-v_T(t)-v_B(t)
$$

Aplicando la transformada de Laplace con condiciones iniciales iguales a
cero:

$$
LsI_L(s)+RI_L(s) = V_C(s)-V_T(s)-V_B(s)
$$

Factorizando la corriente del inductor:

$$
I_L(s)(Ls+R) = V_C(s)-V_T(s)-V_B(s)
$$

Se define la entrada efectiva del circuito de carga como:

$$
U_C(s)=V_C(s)-V_T(s)-V_B(s)
$$

Por lo tanto, la corriente del inductor se expresa como:

$$
I_L(s)=\frac{U_C(s)}{Ls+R}
$$

Finalmente, la función de transferencia del circuito de carga es:

$$
H_C(s) = \frac{I_L(s)}{U_C(s)} = \frac{1}{Ls+R}
$$

### 2. Circuito de descarga

El análisis del circuito de descarga se realiza de manera semejante al del
circuito de carga. Sin embargo, durante la descarga la batería funciona como
fuente de energía y la corriente circula en sentido contrario.

Para comparar ambas etapas se mantiene como referencia positiva el sentido de
la corriente utilizado en el circuito de carga. Por esta razón, la corriente
de descarga aparece con signo negativo.

En este caso, la ecuación diferencial puede escribirse como:

$$
L\frac{di_L(t)}{dt}+R\cdot i_L(t) = v_T(t)+v_D(t)-v_B(t)
$$

donde $v_D(t)$ representa la tensión presente en la salida del circuito de
descarga.

Aplicando la transformada de Laplace con condiciones iniciales iguales a cero:

$$
LsI_L(s)+RI_L(s) = V_T(s)+V_D(s)-V_B(s)
$$

Factorizando la corriente del inductor:

$$
I_L(s)(Ls+R) = V_T(s)+V_D(s)-V_B(s)
$$

Se define la entrada efectiva del circuito de descarga como:

$$
U_D(s)=V_B(s)-V_T(s)-V_D(s)
$$

Debido a que:

$$
V_T(s)+V_D(s)-V_B(s)=-U_D(s)
$$

la corriente del inductor queda expresada como:

$$
I_L(s)=-\frac{U_D(s)}{Ls+R}
$$

Por lo tanto, la función de transferencia del circuito de descarga es:

$$
H_D(s) = \frac{I_L(s)}{U_D(s)} = -\frac{1}{Ls+R}
$$

El signo negativo indica que la corriente de descarga circula en sentido
contrario a la referencia de corriente definida para el proceso de carga.

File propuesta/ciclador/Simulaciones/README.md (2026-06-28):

## Simulaciones

Para validar el funcionamiento del circuito ciclador y preparar la
implementación del sistema de control, se desarrollaron dos modelos principales
en PLECS: `simulacion_control` y `hardware_in_the_loop`.

### Simulación del sistema de control

El archivo `simulacion_control` contiene el modelo del circuito de carga de la
batería junto con su respectivo lazo de control de corriente.

En esta simulación se implementa un controlador PI acompañado de una rama de
prealimentación. El controlador recibe como entrada la diferencia entre la
corriente de referencia y la corriente medida en el inductor. A partir de este
error, genera la señal de control necesaria para accionar el transistor de
potencia y regular la corriente suministrada a la batería.

La rama de prealimentación utiliza información del circuito para generar una
acción de control inicial cercana al valor requerido. Por su parte, el
controlador PI corrige el error restante y compensa las perturbaciones o
variaciones que puedan presentarse durante el proceso de carga.

El objetivo principal de esta simulación es comprobar que la corriente del
inductor pueda seguir adecuadamente la referencia establecida, manteniendo una
respuesta estable y evitando cambios bruscos que puedan afectar la batería o
los componentes del circuito.

Mediante este modelo se pueden analizar aspectos como:

- El seguimiento de la corriente de referencia.
- El tiempo de establecimiento del sistema.
- El sobreimpulso de la corriente.
- La respuesta ante cambios en la referencia.
- La capacidad del controlador para corregir perturbaciones.
- El comportamiento de la tensión de control aplicada al transistor.

Esta simulación permite ajustar los parámetros del controlador antes de
realizar pruebas con el circuito físico.

En la **Figura 1** se tiene el sistema de control utilizado junto con el circuito de simulación en donde se simula el comportamiento de los sensores de corriente para recibir en el sistema de control las mismas señales que va recibir el ESP32, por lo que las señales que se simulan son proporcionales a las que se van a tener las pruebas de `hardware_in_the_loop` y en el circuito físico. 

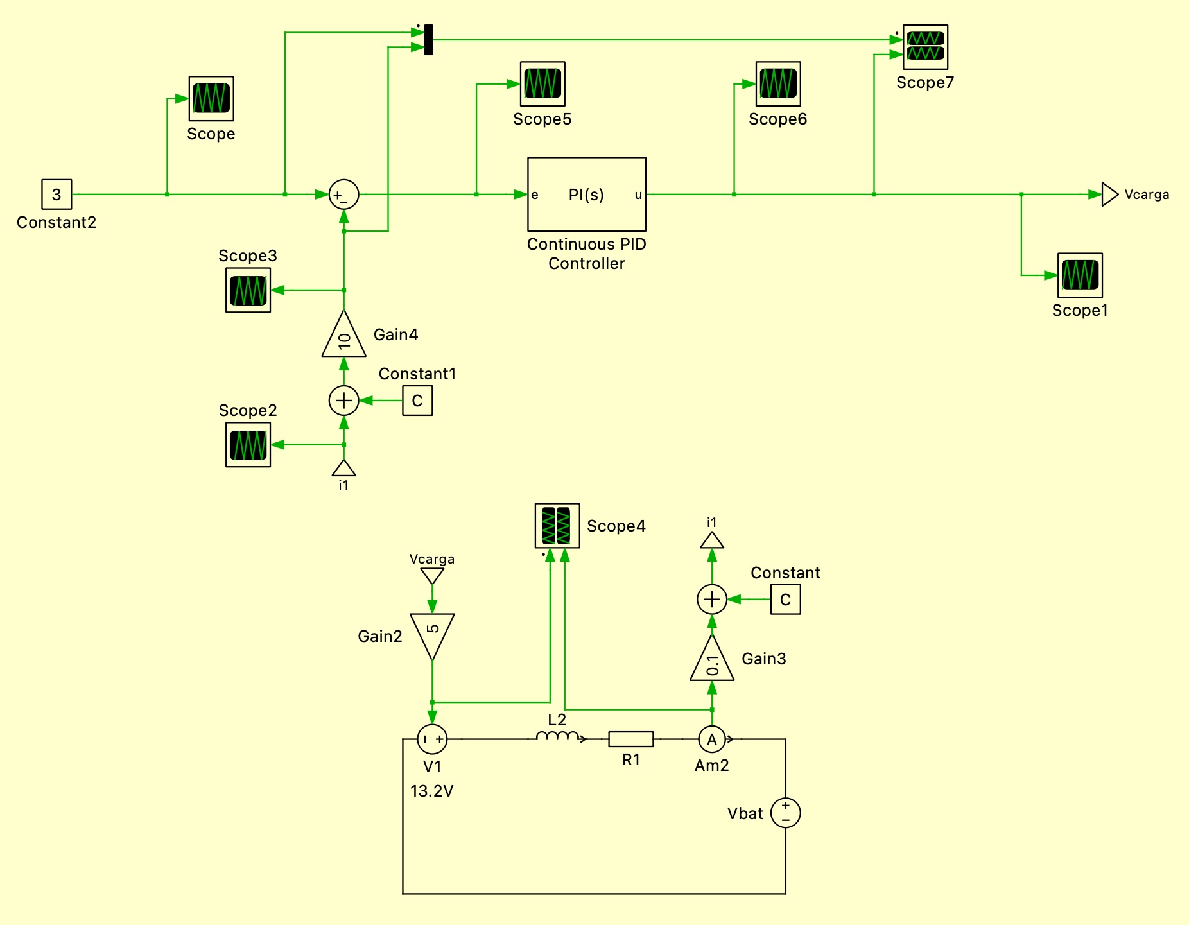
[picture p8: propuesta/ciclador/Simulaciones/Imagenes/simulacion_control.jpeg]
Circuito ciclador y sistema de control implementado en Plecs


En la **Figura 2** se tienen dos gráficas, la de arriba muesta en verde la referencia de corriente y la roja muestra la corriente medida del sensor de carga. En donde se puede ver que la señal logra seguir correctamente la referencia sin generar sobresalto y con error en estadoe stacionario de cero.
Por otro lado, en la gráfica de abajo se tiene la señal de salida del controlador PI, la cual es bastante pequeña debido a que el error se corrige antes de entrar al control PI, por lo que el control es bastante eficiente por el hecho de que se puede medir la perdutbación y corregirla desde antes, logrnado un sistema mas estable ante perturbaciones. 

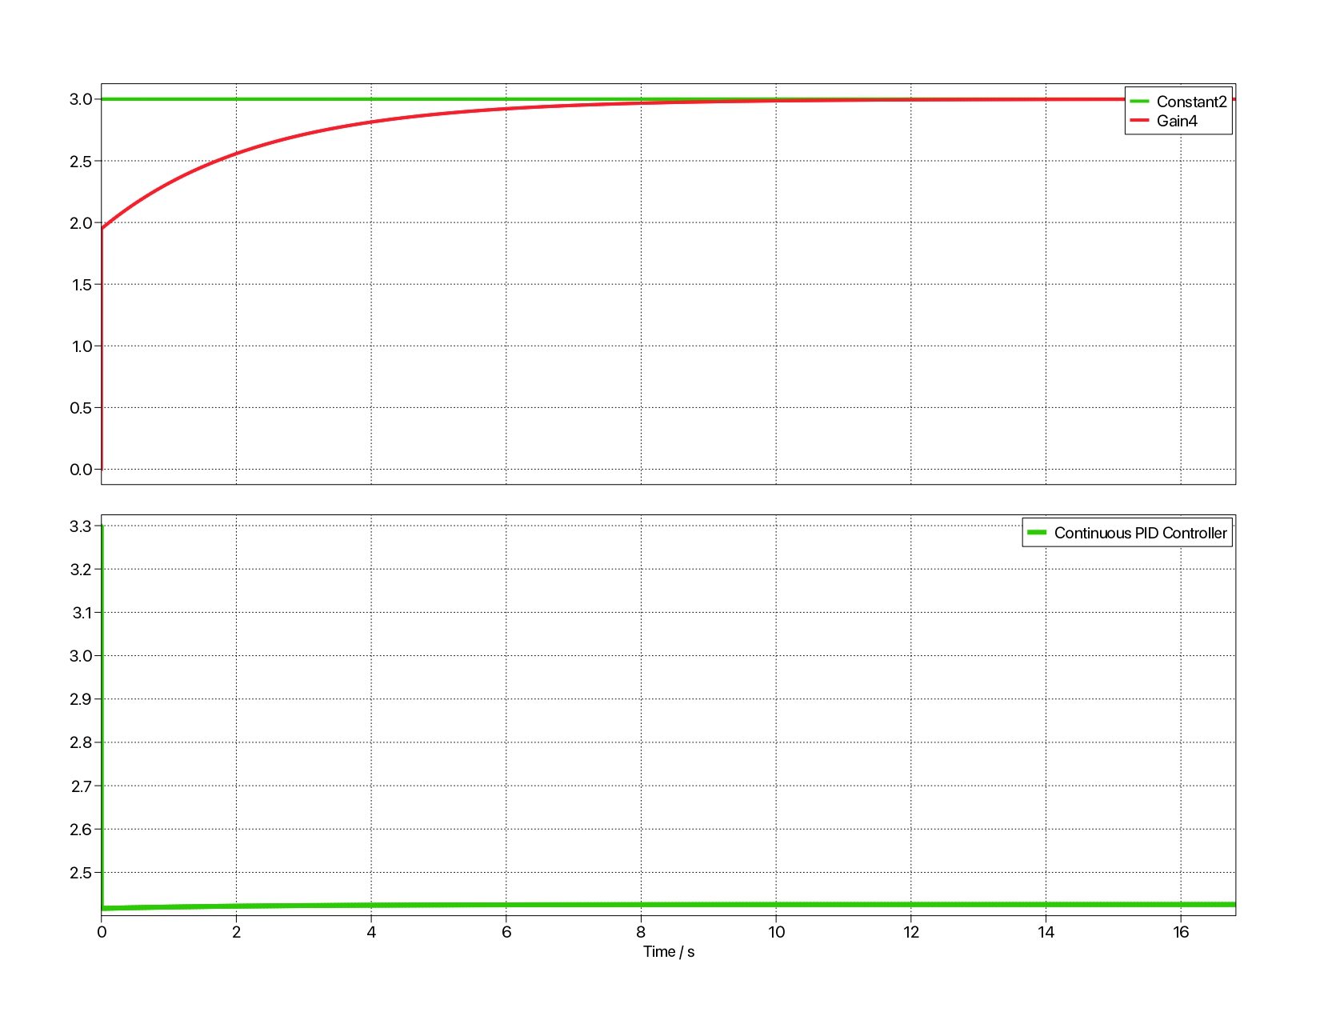
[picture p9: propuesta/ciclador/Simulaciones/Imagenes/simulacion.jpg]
Circuito ciclador y sistema de control implementado en Plecs


### Simulación Hardware-in-the-Loop

El archivo `hardware_in_the_loop` contiene una propuesta de simulación en tiempo
real del sistema completo mediante una arquitectura
**Hardware-in-the-Loop (HIL)**.

El objetivo de esta prueba es representar mediante microcontroladores las
diferentes partes del sistema antes de conectar el controlador desarrollado por
el grupo a la PCB y a una batería física.

La arquitectura propuesta estará formada por tres elementos principales:

1. **C2000 encargado del circuito ciclador:** ejecutará en tiempo real el modelo
   eléctrico del circuito implementado en la PCB. Este modelo representará el
   comportamiento del transistor, el inductor, las resistencias y los demás
   componentes de la etapa de potencia.

2. **ESP32 encargado del sistema de control:** ejecutará el algoritmo de control
   diseñado por el equipo de programación. El ESP32 recibirá las variables
   medidas del sistema, calculará la acción de control y enviará la señal
   correspondiente al modelo del circuito ciclador.

De esta manera, el C2000 simulará el circuito de la PCB y el ESP32 realizará el control
de corriente.

```mermaid
flowchart TD
    REF["Referencia de corriente"] --> ESP32

    ESP32["ESP32<br/>Sistema de control"]
    CICLO["C2000 N.° 1<br/>Modelo del circuito ciclador<br/>Carga y descarga"]

    ESP32 -->|"Señal de control"| CICLO
    CICLO -->|"Señales simuladas de los sensores"| ESP32

```

La simulación HIL permitirá evaluar el controlador utilizando señales y
dispositivos físicos, pero sin conectar inicialmente una batería real ni la
etapa de potencia definitiva.

Con esta prueba se busca verificar:

* La comunicación entre los microcontroladores.
* La correcta lectura de las señales de tensión y corriente.
* La generación de la señal de control por parte del ESP32.
* El seguimiento de la corriente de referencia.
* La respuesta del controlador ante perturbaciones.
* El escalamiento de las señales analógicas entre los dispositivos.
* La estabilidad del sistema durante los procesos de carga y descarga.
* El comportamiento del controlador antes de conectarlo a la PCB física.

Esta arquitectura reduce el riesgo de dañar la batería, la PCB o los
componentes de potencia durante las primeras pruebas. Además, permite detectar
errores de programación, comunicación, escalamiento y control antes de realizar
la integración final del sistema.

En la **Figura 3** se tiene el circuito utilizado para hacer las pruebas hardware in the loop con sus respectivos puertos para comunicación con el C2000. 

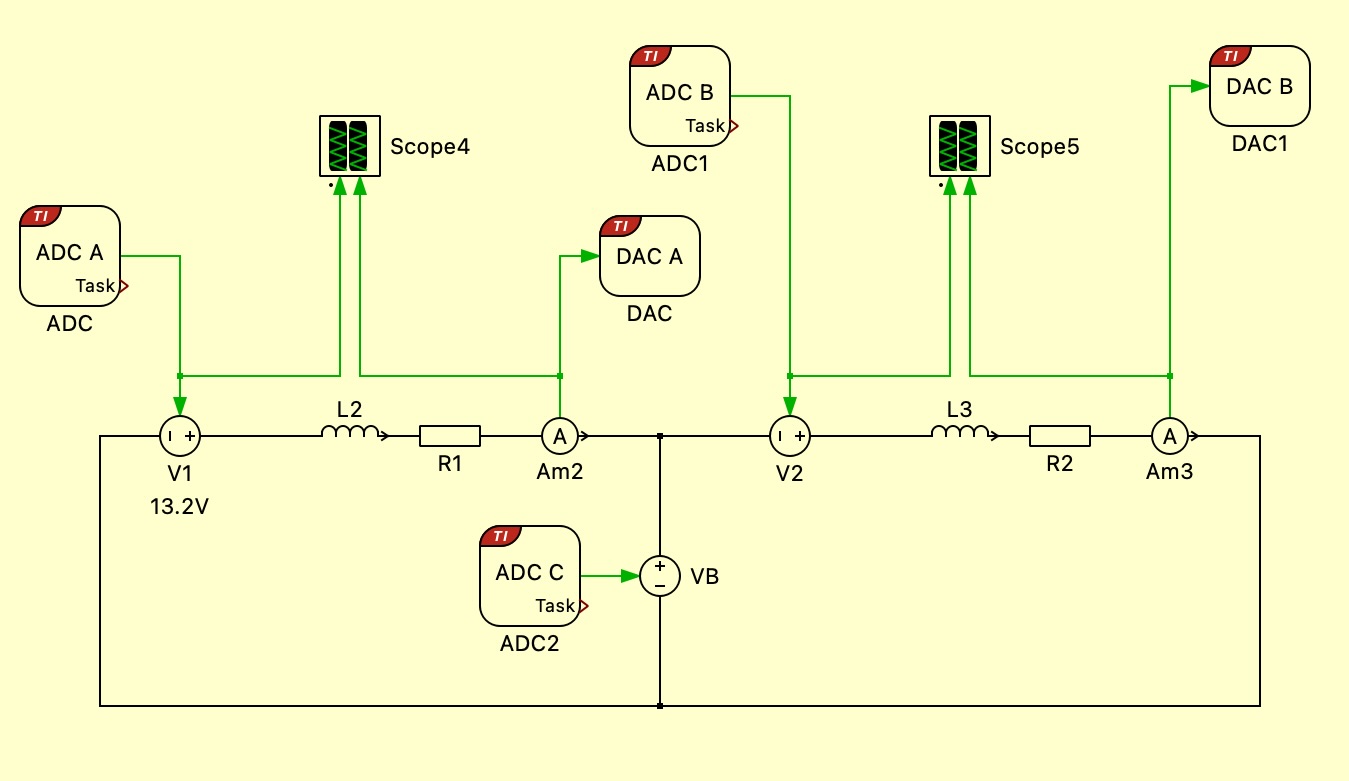
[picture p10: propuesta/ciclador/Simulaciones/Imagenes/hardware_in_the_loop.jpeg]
Circuito de carga y descarga de la batería para pruebas


### Conexión para la prueba Hardware-in-the-Loop

Para realizar la prueba **Hardware-in-the-Loop**, el modelo del circuito
ciclador se ejecuta en el C2000. Este C2000 recibe desde el ESP32 las señales
de control de carga y descarga, y devuelve al ESP32 las señales simuladas de
los sensores.

De esta forma, el ESP32 trabaja como si estuviera conectado a la PCB física,
pero en realidad las señales de corriente y tensión son generadas por el modelo
del circuito ejecutado en el C2000.

La conexión entre el ESP32 y el C2000 se realiza mediante señales analógicas.
Las señales de control salen desde el ESP32 hacia el C2000, mientras que las
señales simuladas de sensores salen desde el C2000 hacia el ESP32.

| Pin del C2000 | Dirección de la señal | Descripción |
|---|---|---|
| Pin 66 | ESP32 → C2000 | Señal de control de carga enviada desde el ESP32. |
| Pin 65 | ESP32 → C2000 | Señal de control de descarga enviada desde el ESP32. |
| Pin 30 | C2000 → ESP32 | Señal simulada del sensor de corriente de carga. |
| Pin 70 | C2000 → ESP32 | Señal simulada del sensor de corriente de descarga. |
| Pin 32 | C2000 → ESP32 | Señal simulada de tensión de la batería. |

Es importante que todas las tierras del sistema estén conectadas entre sí. La
referencia `GND` del ESP32 debe estar conectada a la referencia `GND` del
C2000. Si las tierras no se conectan correctamente, las señales analógicas no
tendrán la misma referencia y las mediciones recibidas por el ESP32 pueden ser
incorrectas.

Antes de realizar la prueba se debe verificar que las señales analógicas estén
dentro del rango permitido por cada dispositivo. En particular, las señales que
ingresan al ESP32 deben mantenerse entre `0 V` y `3.3 V`.

La prueba HIL permite verificar el algoritmo de control sin conectar todavía la
PCB física ni una batería real. Con esta configuración se puede comprobar si el
ESP32 genera correctamente las señales de carga y descarga, y si responde de
forma adecuada a las señales simuladas de corriente y tensión entregadas por el
C2000.

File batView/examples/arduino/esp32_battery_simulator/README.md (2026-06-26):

# ESP32 Battery Simulator for batView

This Arduino sketch makes an ESP32 behave like a simulated battery source for batView over USB serial.

## Upload

1. Open `esp32_battery_simulator.ino` in Arduino IDE.
2. Select your ESP32 board and USB serial port.
3. Upload the sketch.
4. Open batView and connect to the ESP32 serial port at `115200`.

## Behavior

- Answers `#CONNECTION` with `#ACK,CONNECTION`.
- Accepts the selected battery profile from batView.
- Simulates charge with `#LOAD,<targetPercent>`.
- Simulates discharge with `#UNLOAD,<targetPercent>`.
- Simulates repeated charge/discharge cycles with `#CICLE,...`.
- Streams telemetry as `#DATA,<voltage>,<current>,<timestampMs>,<state>,<completedCycles>`.

Current is positive while charging and negative while discharging.

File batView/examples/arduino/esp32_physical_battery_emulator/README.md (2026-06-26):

# ESP32 Physical Battery Emulator Controller

This sketch is for the second-ESP32 setup where one ESP32 runs the batView protocol/control side and another ESP32 emulates a battery electrically.

The ESP32 cannot act as a battery by itself. It must drive external hardware that can source and sink current safely.

## Expected Hardware

- Voltage divider from the emulator battery terminals into `PIN_VOLTAGE_SENSE`.
- Bidirectional current sensor into `PIN_CURRENT_SENSE`.
- Source stage driven by `GPIO32`, such as a controlled buck/boost supply.
- Sink stage driven by `GPIO33`, such as a MOSFET electronic load or bidirectional converter.
- C2000/C200 ADC input connected to `GPIO25` for scaled virtual battery voltage.
- Optional C2000/C200 ADC input connected to `GPIO26` for scaled current.
- Optional enable pin on `PIN_ENABLE`.

## Model

- Positive measured current means charging.
- Negative measured current means discharging.
- SOC is updated by coulomb counting.
- Open-circuit voltage comes from a 12 V battery SOC table.
- Terminal voltage target is:

```text
Vterminal = Voc + I * Rinternal
```

That means terminal voltage rises during charge and drops during discharge.

For this project model:

- Empty battery: `12.0 V`
- Full battery: `13.8 V`
- ESP32 analog output range: `0.0 V` to `3.3 V`
- C2000 voltage gain to recover battery voltage: `4.1818`

So:

```text
Vbattery = Vadc * 4.1818
Vadc = Vbattery / 4.1818
```

Expected ADC voltages:

```text
12.0 V battery -> 2.87 V at C2000 ADC
13.8 V battery -> 3.30 V at C2000 ADC
```

Current on `GPIO26` is centered:

```text
0.00 V = maximum discharge current
1.65 V = 0 A
3.30 V = maximum charge current
```

## Calibration

Before connecting to the control ESP32 power stage, adjust:

- `VOLTAGE_DIVIDER_RATIO`
- `CURRENT_ZERO_ADC_V`
- `CURRENT_SENSOR_V_PER_A`
- `CURRENT_SIGN`
- `MAX_CHARGE_CURRENT_A`
- `MAX_DISCHARGE_CURRENT_A`
- `KP` and `KI`

Start with current-limited supplies and low PWM duty limits while tuning.

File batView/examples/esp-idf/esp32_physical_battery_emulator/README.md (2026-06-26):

# ESP-IDF Physical Battery Emulator

This is the `.c` / ESP-IDF version of the physical battery emulator controller.

## Pin Map

```text
GPIO25 / DAC1 -> C2000 ADC, scaled virtual battery voltage
GPIO26 / DAC2 -> C2000 ADC, optional scaled current
GPIO34 / ADC1 -> physical terminal voltage measurement
GPIO35 / ADC1 -> physical terminal current measurement
GPIO32 / PWM  -> external source-stage control
GPIO33 / PWM  -> external sink-stage control
GPIO27        -> optional enable
```

## C2000 Gain

Use this in the C2000:

```c
Vbattery = Vadc * 4.1818f;
```

Expected mapping:

```text
12.0 V battery -> 2.87 V ADC
13.8 V battery -> 3.30 V ADC
```

## Build

From this folder:

```sh
idf.py set-target esp32
idf.py build
idf.py flash monitor
```

Calibrate the constants at the top of `main/esp32_physical_battery_emulator.c` before connecting to higher-power hardware.

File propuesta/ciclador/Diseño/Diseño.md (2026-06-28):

## Diseño del circuito

La topología implementada se muestra en la **Figura 1**. En el lado izquierdo se encuentra el circuito encargado de la carga de la batería, mientras que en el lado derecho se ubica el circuito de descarga.

Ambas etapas presentan una estructura similar, debido a que en los dos casos se requiere controlar la corriente que circula hacia o desde la batería.

### 1. Etapa de carga

Al analizar la trayectoria de corriente del circuito de carga en sentido horario, se encuentran los siguientes elementos:

1. **Fuente de tensión:** proporciona la energía necesaria para cargar la batería.
2. **Transistor de potencia:** regula el paso de corriente mediante su conmutación.
3. **Inductor:** limita las variaciones bruscas de corriente y almacena energía.
4. **Batería:** recibe la corriente suministrada por el circuito de carga.

Desde el punto de vista del sistema de control, el transistor corresponde al **actuador**, ya que modifica la corriente del circuito según la señal de control aplicada.

### 2. Etapa de descarga

La etapa de descarga presenta una estructura semejante a la etapa de carga. En este caso, el transistor regula la corriente que sale de la batería, mientras que el inductor limita sus variaciones bruscas.

Debido a la relación entre la tensión aplicada al inductor y la variación de su corriente, es posible controlar la corriente de carga o descarga mediante la conmutación del transistor.

### 3. Acondicionamiento de la señal de control

La señal de control proveniente del ESP32 posee un rango de tensión entre **0 V y 3.3 V**.

Esta señal se introduce en un amplificador operacional configurado como **amplificador no inversor**, formado por resistencias de **1 kΩ** y **3.3 kΩ**. La ganancia del amplificador es:

$$
A_v = 1 + \frac{3\ \text{k}\Omega}{1\ \text{k}\Omega} = 4.3
$$

Por lo tanto, la tensión máxima de salida es aproximadamente:

$$
V_{\text{salida}} = 4.3(3.3\ \text{V}) = 14.2\ \text{V}
$$

### 4. Accionamiento del transistor

La amplificación es necesaria para proporcionar un nivel de tensión adecuado para el accionamiento del transistor.

Durante los procesos de carga y descarga, la tensión de control debe ser suficientemente alta con respecto al nodo ubicado entre el transistor y el inductor. Esto permite:

* Garantizar la correcta activación del transistor.
* Regular la corriente del circuito.
* Controlar la corriente que circula hacia o desde la batería.

## Diagrama del circuito

Circuito de carga y descarga de la batería

*Figura 1. Topología del circuito de carga y descarga de la batería.*

## Función de transferencia

### 1. Ecuación de tensiones

Aplicando la **Ley de Voltajes de Kirchhoff** en sentido horario sobre el circuito de carga, se obtiene:

$$
-v_C(t)+v_T(t)+v_L(t)+v_R(t)+v_B(t)=0
$$

La tensión en el inductor se expresa como:

$$
v_L(t)=L\frac{di_L(t)}{dt}
$$

Por otra parte, la caída de tensión en la resistencia parásita está dada por:

$$
v_R(t)=R\cdot i_L(t)
$$

Sustituyendo ambas expresiones:

$$
-v_C(t)+v_T(t)+L\frac{di_L(t)}{dt}+R\cdot i_L(t)+v_B(t)=0
$$

Al reorganizar:

$$
L\frac{di_L(t)}{dt}+R\cdot i_L(t) = v_C(t)-v_T(t)-v_B(t)
$$

### 2. Transformada de Laplace

Aplicando la transformada de Laplace con condiciones iniciales iguales a cero:

$$
LsI_L(s)+RI_L(s) = V_C(s)-V_T(s)-V_B(s)
$$

Factorizando:

$$
I_L(s)(Ls+R) = V_C(s)-V_T(s)-V_B(s)
$$

Despejando la corriente:

$$
I_L(s) = \frac{V_C(s)-V_T(s)-V_B(s)}{Ls+R}
$$

### 3. Función de transferencia

Se define la entrada efectiva como:

$$
U(s)=V_C(s)-V_T(s)-V_B(s)
$$

Entonces:

$$
H(s) = \frac{I_L(s)}{U(s)} = \frac{1}{Ls+R}
$$

La forma estándar es:

$$
H(s) = \frac{\frac{1}{R}}{\frac{L}{R}s+1} = \frac{K}{\tau s+1}
$$

donde:

$$
K=\frac{1}{R}
$$

$$
\tau=\frac{L}{R}
$$

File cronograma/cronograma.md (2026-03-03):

# Cronograma (Sujeto a Cambios)

En este apartado se estipulan las actividades planteadas para cada semana de avance del proyecto.

| Semana<br>Actividad del Curso |Ciclador  | Protocolo Comunicación | Software |
|:---:|---|---|---|
| 1 |- Seleción de componentes<br>- Diseño y simulación de circuitos <br>- Trabajo en la PCB |- Propuesta de Protocolo de Comunicación<br> - Implementación en ESP32  |- Selección de estructura para el programa<br> - Diagrama de Flujo para el Front-End del Software| 
| 2 |- Finalización de la PCB<br> - Pedido de PCB | - Primera Implementación del Protocolo en el ESP32<br> - Prueba de Envío de Datos mediante Compu - USB - ESP32 | - Implementación del Front-End del Software<br> - Elaboración de Diagrama de Flujo para el Back-End del Software|
| 3<br>Visita a Proyectos  |- Elaboración de Bitácora #1 <br> - Trabajo en la Documentación del Proyecto  | - Elaboración de Bitácora #1 <br> - Trabajo en la Documentación del Proyecto  | - Elaboración de Bitácora #1 <br> - Trabajo en la Documentación del Proyecto|
| 4<br>Visita a Proyectos<br>Entrega Bitácora #1 | - Realizar pruebas de la PCB de Manera Física <br> - Toma de Datos para Elaboración de la Documentación | - Prueba del Protocolo de Comunicación Junto con la PCB <br> - Toma de Datos para Elaboración de Documentación |- Confección de la Lógica del Back-End <br> - Confección de un Plan de Pruebas para Garantizar el Correcto Funcionamiento del SW  |
| 5  |- Prueba con la Primera Batería<br> - Toma de Datos para la Elaboración de la Documentación |<br> - Prueba del Prueba del Protocolo junto con la Batería <br> - Toma de Datos para la Elaboración de la Documentación | - Diseño del Control de Datos Recibidos Mediante USB, Provenientes del Protocolo de Comunicación<br> - Elaboración de Documentación del Proceso de Adquisición de Datos |
| 6<br>Visita a Proyectos |- Reestructuración de la PCB para Posible Optimización<br> - Documentación del Proceso |- Depuración del Protocolo de Comunicación<br> - Documentación del Proceso |- Depuración del Front y Back-End del Software<br> - Documentación del Proceso|
| 7<br>Visita a Proyectos<br>Entrega Bitácora #2 | | | |
| 8 | | | |
| 9<br>Visita a Proyectos  | | | |
| 10<br>Visita a Proyectos<br>Entrega Bitácora #3 | | | |
| 11<br>Informe y Resumen | | | |
| 12<br>Visita a Proyectos | | | |
| 13<br>Visita a Proyectos<br>Entrega Bitácora #4  | | | |
| 14<br>Pósteres  | | | |
| 15<br>Visita a Proyectos | | | |
| 16<br>Visita a Proyectos<br>Entrega Bitácora #5 | | | |
| 17<br>Presentación Final | Presentación Final| Presentación Final | Presentación Final |

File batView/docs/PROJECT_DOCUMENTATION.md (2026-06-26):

# Documentación del Proyecto

## Resumen

batView es una aplicación de escritorio para supervisar pruebas de baterías controladas por un ESP32.  
La aplicación se comunica por puerto serial, valida un protocolo simple basado en texto y presenta un flujo guiado de operación en la UI.

## Objetivos funcionales

- Establecer conexión con un ESP32 por USB/UART.
- Confirmar handshake mediante `ACK`.
- Enviar comandos de selección de batería y modo de trabajo.
- Iniciar operaciones de carga, descarga o ciclado.
- Detener cualquier operación activa mediante `#STOP`.
- Recibir y almacenar telemetría.
- Exportar resultados a CSV.
- Exportar resultados completos a MAT y XLSX.
- Exportar gráficas derivadas a CSV, MAT, XLSX y PNG.

## Flujo de usuario

1. Seleccionar puerto serial.
2. Conectar con el ESP32.
3. Crear y elegir un perfil de batería.
4. Elegir función:
   - Carga
   - Descarga
   - Ciclado
5. Configurar porcentaje o ciclos según corresponda.
6. Iniciar operación.
7. Detener cuando sea necesario.
8. Exportar datos si se desea.

## Flujo de comunicación

### Conexión

- App: `#CONNECTION`
- ESP32: `#ACK,CONNECTION` o `#ACK,CONECTION`
- Estado adicional aceptado: `#STATUS,CONNECTED,ESP32_READY`

La app reintenta el handshake automáticamente para tolerar ESP32 que reinician al abrir el puerto.

### Perfil de batería

- App: `#Battery,<BatteryNameID>,<V@max>,<V@min>,<Amax>`
- ESP32: `#ACK,Battery`

### Inicio de operación

- Carga:
  - App: `#LOAD,<0-100>`
  - ESP32: `#ACK,LOAD`
- Descarga:
  - App: `#UNLOAD,<0-100>`
  - ESP32: `#ACK,UNLOAD`
- Ciclado:
  - App: `#CICLE,0,0` o `#CICLE,1,<n>`
  - ESP32: `#ACK,CICLE`

### Detención

- App: `#STOP`
- ESP32: `#ACK,STOP`

### Telemetría

Se soportan dos variantes:

- `#DATA,<tension>,<corriente>,<timestamp>`
- `#DATA,<tension>,<corriente>,<timestamp>,<estado>,<ciclos>`

#### Origen y uso de los campos

Todos los campos de telemetría usados por la aplicación provienen del ESP32:

- `tension`
- `corriente`
- `timestamp`
- `estado`
- `ciclos`

La aplicación parsea esas tramas y las convierte a la estructura `Measurement` para conservarlas en memoria, exportarlas y graficarlas.

En particular:

- `timestamp` es esperado desde el ESP32 en milisegundos
- para la visualización de gráficas, la app convierte ese valor a segundos
- esa conversión solo afecta la presentación del eje X, no el valor base recibido ni el dato almacenado

## Manejo de errores

La aplicación distingue entre:

- fallo al abrir el puerto serial
- fallo al configurar el puerto
- fallo al escribir en serial
- timeout esperando `ACK`
- error explícito enviado por el ESP32

Cuando el backend serial reporta un error del sistema, la app conserva el detalle para facilitar diagnóstico.

## Componentes principales

### UI

- `src/ui/BatViewApp.*`
  Punto de entrada wxWidgets.

- `src/ui/frames/MainFrame.*`
  Ventana principal y flujo operativo.

- `src/ui/panels/ConnectionPanel.*`
  Selector de puerto y estado de conexión.

- `src/ui/dialogs/ExportDialog.*`
  Diálogo de exportación.

### Servicios

- `src/core/services/ConnectionService.*`
  Conexión serial y handshake.

- `src/core/services/ProtocolSessionService.*`
  Envío de comandos con espera de `ACK`.

- `src/core/services/AcquisitionService.*`
  Lectura de telemetría en segundo plano.

- `src/core/services/ExportService.*`
  Exportación por formato.

### Protocolo

- `src/core/protocol/TextProtocolCodec.*`
  Construcción y validación de mensajes del protocolo.

- `src/core/protocol/TextMessageParser.*`
  Conversión de tramas `#DATA` a mediciones.

### Infraestructura

- `src/infrastructure/serial/PosixSerialPort.*`
  Implementación serial real para entornos POSIX.

- `src/infrastructure/serial/Win32SerialPort.*`
  Implementación serial real para Windows.

- `src/infrastructure/serial/SerialPortStub.*`
  Implementación simulada para modo consola y pruebas tempranas.

- `src/infrastructure/csv/CsvExporter.*`
  Exportación CSV.

- `src/infrastructure/logging/ConsoleLogger.*`
  Logging a consola.

- `src/infrastructure/python/PythonPlotEngine.*`
  Render de gráficas y exportación XLSX mediante Python embebido cuando está disponible.

## Build y ejecución

### Flujo recomendado

La forma recomendada de construir la app completa es usar el flujo automático de un solo comando.

#### macOS / Linux

```bash
./build_app.sh
```

#### Windows

```powershell
powershell -ExecutionPolicy Bypass -File .\build_app.ps1
```

Ese flujo:

- detecta el sistema operativo;
- prepara Python embebido para exportación `XLSX` y render `PNG`;
- instala `Pillow` y `openpyxl` dentro del proyecto;
- construye la app;
- genera el paquete final en `dist/`.

Nota:

- en la primera ejecución normalmente se necesita internet para descargar `Pillow` y `openpyxl`;
- esas dependencias quedan guardadas en `python/runtime/`.

### Dependencias base por instalar

Para preparar una computadora desde cero, usa los scripts de instalación del proyecto:

```powershell
powershell -ExecutionPolicy Bypass -File .\install_windows.ps1
```

```bash
./install_macos.sh
./install_linux.sh
```

La guía de instaladores está en [BUILD_INSTALLER.md](./BUILD_INSTALLER.md).

Si prefieres instalar dependencias manualmente, usa estas referencias:

#### macOS

```bash
xcode-select --install
brew install cmake wxwidgets python
```

#### Ubuntu / Debian

```bash
sudo apt update
sudo apt install -y cmake g++ make pkg-config libwxgtk3.2-dev libgtk-3-dev python3 python3-pip
```

#### Windows

- Visual Studio 2022 con `Desktop development with C++`
- CMake
- Python 3
- wxWidgets compatible con el compilador instalado

### App principal

### macOS

```bash
cmake -S . -B build-release -DBATVIEW_ENABLE_WX=ON -DCMAKE_BUILD_TYPE=Release
cmake --build build-release --config Release
open build-release/batView.app
```

### Linux

```bash
cmake -S . -B build-release -DBATVIEW_ENABLE_WX=ON -DCMAKE_BUILD_TYPE=Release
cmake --build build-release --config Release
./build-release/batView
```

### Windows

```powershell
cmake -S . -B build-release -DBATVIEW_ENABLE_WX=ON -DCMAKE_BUILD_TYPE=Release
cmake --build build-release --config Release
.\build-release\Release\batView.exe
```

### Empaquetado para distribución

```bash
cmake -S . -B build-release -DBATVIEW_ENABLE_WX=ON -DCMAKE_BUILD_TYPE=Release -DBATVIEW_PACKAGE_FORMAT=PORTABLE
cmake --build build-release --config Release --target package
```

El artefacto final se genera en `dist/`, fuera de la carpeta `build-release/`.

### Tests

```bash
cmake -S . -B build-tests -DBATVIEW_BUILD_TESTS=ON
cmake --build build-tests --config Release
ctest --test-dir build-tests --output-on-failure
```

## Ejemplos de hardware

Hay proyectos de prueba listos para subir al ESP32 en:

- `examples/arduino/esp32_batview_test`
- `examples/platformio/esp32_batview_test`

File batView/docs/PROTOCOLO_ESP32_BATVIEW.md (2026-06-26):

# Protocolo de comunicacion ESP32 <-> batView

Este documento describe el protocolo serial que debe implementar el firmware del
ESP32 para comunicarse correctamente con la aplicacion de escritorio batView.

## 1. Configuracion serial

- Medio: USB/UART.
- Baud rate: `115200`.
- Formato: `8N1`.
- Control de flujo: ninguno.
- Codificacion: texto ASCII/UTF-8 simple.
- Cada trama debe enviarse como una linea completa.
- Cada linea debe terminar con salto de linea `\n`.
- Se permite `\r\n`, pero se recomienda usar solo `\n`.

Todas las tramas validas empiezan con `#`.

Ejemplo:

```text
#ACK,CONNECTION\n
```

## 2. Reglas generales de formato

1. No agregar espacios antes, despues ni entre campos.
2. Separar campos con coma `,`.
3. No usar comas dentro de campos de texto.
4. Enviar una sola trama por linea.
5. Responder cada comando del PC con un `#ACK,...` o un `#ERROR,...`.
6. Los nombres de comandos y ACK deben respetar mayusculas y minusculas como se
   muestran en este documento.

batView es tolerante durante la conexion inicial y acepta algunas variantes
historicas, pero el firmware nuevo debe seguir la forma recomendada.

## 3. Comandos enviados por batView al ESP32

### 3.1 Conexion

batView envia:

```text
#CONNECTION
```

Respuesta recomendada del ESP32:

```text
#ACK,CONNECTION
```

Compatibilidad aceptada por batView durante conexion:

```text
#ACK,CONECTION
#ACK,DATA
```

`#ACK,CONECTION` se acepta por compatibilidad con un typo anterior. No usarlo en
firmware nuevo.

`#ACK,DATA` se acepta durante reconexion porque algunos firmware quedan en modo
de telemetria y responden asi al recibir `#CONNECTION`. Aun asi, la respuesta
recomendada para firmware nuevo es siempre `#ACK,CONNECTION`.

### 3.2 Perfil de bateria

batView envia:

```text
#Battery,<BatteryNameID>,<Vmax>,<Vmin>,<Amax>
```

Campos:

| Campo | Tipo | Descripcion |
|---|---|---|
| `BatteryNameID` | texto sin comas | Identificador del perfil de bateria. |
| `Vmax` | decimal | Tension maxima de la bateria. Debe ser mayor que `0`. |
| `Vmin` | decimal | Tension minima de la bateria. Debe ser mayor que `0` y menor que `Vmax`. |
| `Amax` | decimal | Corriente maxima permitida. Debe ser mayor que `0`. |

Ejemplo:

```text
#Battery,LiIon_1S,4.2,3.0,1.5
```

Respuesta esperada:

```text
#ACK,Battery
```

### 3.3 Carga

batView envia:

```text
#LOAD,<targetPercent>
```

Campos:

| Campo | Tipo | Descripcion |
|---|---|---|
| `targetPercent` | entero `0` a `100` | Porcentaje objetivo de carga. |

Ejemplo:

```text
#LOAD,80
```

Respuesta esperada:

```text
#ACK,LOAD
```

Despues del ACK, el ESP32 puede empezar a enviar telemetria `#DATA`.

### 3.4 Descarga

batView envia:

```text
#UNLOAD,<targetPercent>
```

Campos:

| Campo | Tipo | Descripcion |
|---|---|---|
| `targetPercent` | entero `0` a `100` | Porcentaje objetivo de descarga. |

Ejemplo:

```text
#UNLOAD,20
```

Respuesta esperada:

```text
#ACK,UNLOAD
```

Despues del ACK, el ESP32 puede empezar a enviar telemetria `#DATA`.

### 3.5 Ciclado

batView soporta dos modos de ciclado.

Modo infinito:

```text
#CICLE,0,0
```

Modo finito:

```text
#CICLE,1,<cycleCount>
```

Campos:

| Campo | Tipo | Descripcion |
|---|---|---|
| Primer campo | `0` o `1` | `0` significa infinito, `1` significa numero fijo de ciclos. |
| `cycleCount` | entero positivo | Cantidad de ciclos cuando el primer campo es `1`. En modo infinito debe ser `0`. |

Ejemplos:

```text
#CICLE,0,0
#CICLE,1,5
```

Respuesta esperada:

```text
#ACK,CICLE
```

Despues del ACK, el ESP32 puede empezar a enviar telemetria `#DATA`.

Nota: el comando se escribe `CICLE`, no `CYCLE`, porque asi esta definido en la
aplicacion actual.

### 3.6 Detener operacion

batView envia:

```text
#STOP
```

Respuesta esperada:

```text
#ACK,STOP
```

Despues de `#ACK,STOP`, el ESP32 debe detener carga, descarga, ciclado y envio de
telemetria continua.

## 4. Tramas enviadas por el ESP32 al PC

### 4.1 ACK

Formato:

```text
#ACK,<token>
```

ACK esperados:

| Comando recibido | ACK que debe responder el ESP32 |
|---|---|
| `#CONNECTION` | `#ACK,CONNECTION` |
| `#Battery,...` | `#ACK,Battery` |
| `#LOAD,...` | `#ACK,LOAD` |
| `#UNLOAD,...` | `#ACK,UNLOAD` |
| `#CICLE,...` | `#ACK,CICLE` |
| `#STOP` | `#ACK,STOP` |

Regla importante: el ACK debe enviarse cuando el comando fue recibido, entendido
y aceptado. Si el comando no se puede ejecutar, enviar `#ERROR,...` en lugar de
un ACK.

### 4.2 Estado

Formato:

```text
#STATUS,<state>,<detail>
```

Campos:

| Campo | Tipo | Descripcion |
|---|---|---|
| `state` | texto sin comas | Estado general del ESP32. |
| `detail` | texto sin comas | Detalle adicional. |

Ejemplos recomendados:

```text
#STATUS,CONNECTED,ESP32_READY
#STATUS,CHARGING,PROCESS_ACTIVE
#STATUS,DISCHARGING,PROCESS_ACTIVE
#STATUS,CYCLING,PROCESS_ACTIVE
#STATUS,FINISHED,CYCLE_COMPLETE
#STATUS,STOPPED,USER_STOP
```

Durante la conexion, batView reconoce como senal de dispositivo listo cualquier
`#STATUS,...` que contenga `ESP32_READY` o `CONNECTED`.

### 4.3 Error

Formato:

```text
#ERROR,<code>,<message>
```

Campos:

| Campo | Tipo | Descripcion |
|---|---|---|
| `code` | texto o numero sin comas | Codigo corto del error. |
| `message` | texto sin comas | Descripcion del error. |

Ejemplos:

```text
#ERROR,INVALID_COMMAND,Comando no reconocido
#ERROR,INVALID_VALUE,Porcentaje fuera de rango
#ERROR,NOT_READY,Perfil de bateria no configurado
```

Si el ESP32 envia `#ERROR,...`, batView considera fallido el comando que estaba
esperando ACK.

### 4.4 Telemetria

Formato corto:

```text
#DATA,<voltage>,<current>,<timestampMs>
```

Formato extendido:

```text
#DATA,<voltage>,<current>,<timestampMs>,<state>,<completedCycles>
```

Campos:

| Campo | Tipo | Descripcion |
|---|---|---|
| `voltage` | decimal | Tension medida por el ESP32. |
| `current` | decimal | Corriente medida por el ESP32. |
| `timestampMs` | entero o decimal | Tiempo en milisegundos generado por el ESP32. |
| `state` | entero | Estado operativo definido por el firmware. Solo en formato extendido. |
| `completedCycles` | entero | Ciclos completados. Solo en formato extendido. |

Ejemplos:

```text
#DATA,4.12,0.85,1520
#DATA,4.10,0.82,1770,1,3
```

Notas importantes:

- batView no inventa ni recalcula `voltage`, `current` ni `timestampMs`.
- batView guarda el `timestampMs` recibido y solo lo convierte a segundos para
  graficar.
- No enviar `#DATA` antes de responder el ACK del comando que inicia la
  operacion.
- Durante una operacion activa, el ESP32 puede enviar `#DATA` continuamente.
- Despues de `#STOP` y `#ACK,STOP`, detener el envio continuo de `#DATA`.

## 5. Flujo recomendado de sesion

### 5.0 Diagrama general

```mermaid
sequenceDiagram
    participant PC as batView PC
    participant ESP as ESP32 Firmware

    PC->>ESP: #CONNECTION
    ESP-->>PC: #ACK,CONNECTION
    ESP-->>PC: #STATUS,CONNECTED,ESP32_READY

    PC->>ESP: #Battery,<BatteryNameID>,<Vmax>,<Vmin>,<Amax>
    ESP-->>PC: #ACK,Battery

    alt Carga
        PC->>ESP: #LOAD,<targetPercent>
        ESP-->>PC: #ACK,LOAD
        ESP-->>PC: #STATUS,CHARGING,PROCESS_ACTIVE
    else Descarga
        PC->>ESP: #UNLOAD,<targetPercent>
        ESP-->>PC: #ACK,UNLOAD
        ESP-->>PC: #STATUS,DISCHARGING,PROCESS_ACTIVE
    else Ciclado
        PC->>ESP: #CICLE,0,0 o #CICLE,1,<cycleCount>
        ESP-->>PC: #ACK,CICLE
        ESP-->>PC: #STATUS,CYCLING,PROCESS_ACTIVE
    end

    loop Mientras la operacion esta activa
        ESP-->>PC: #DATA,<voltage>,<current>,<timestampMs>
        ESP-->>PC: #DATA,<voltage>,<current>,<timestampMs>,<state>,<completedCycles>
    end

    PC->>ESP: #STOP
    ESP-->>PC: #ACK,STOP
    ESP-->>PC: #STATUS,STOPPED,USER_STOP
```

### 5.1 Conexion inicial

```text
PC:    #CONNECTION
ESP32: #ACK,CONNECTION
ESP32: #STATUS,CONNECTED,ESP32_READY
```

### 5.2 Seleccion de bateria

```text
PC:    #Battery,LiIon_1S,4.2,3.0,1.5
ESP32: #ACK,Battery
```

### 5.3 Inicio de carga

```text
PC:    #LOAD,80
ESP32: #ACK,LOAD
ESP32: #STATUS,CHARGING,PROCESS_ACTIVE
ESP32: #DATA,3.85,0.65,1000
ESP32: #DATA,3.86,0.66,2000
```

### 5.4 Detener operacion

```text
PC:    #STOP
ESP32: #ACK,STOP
ESP32: #STATUS,STOPPED,USER_STOP
```

## 6. Flujo recomendado de reconexion

### 6.1 Diagrama de reconexion

```mermaid
sequenceDiagram
    participant PC as batView PC
    participant ESP as ESP32 Firmware

    PC->>ESP: #CONNECTION

    alt Respuesta recomendada
        ESP-->>PC: #ACK,CONNECTION
        ESP-->>PC: #STATUS,CONNECTED,ESP32_READY
        Note over PC,ESP: batView marca la conexion como exitosa
    else Compatibilidad si el ESP32 estaba enviando datos
        ESP-->>PC: #ACK,DATA
        Note over PC,ESP: batView tambien acepta esta respuesta durante reconexion
    else Solo estado listo
        ESP-->>PC: #STATUS,CONNECTED,ESP32_READY
        PC->>ESP: #CONNECTION
        ESP-->>PC: #ACK,CONNECTION
    else Error
        ESP-->>PC: #ERROR,<code>,<message>
        Note over PC,ESP: batView muestra error y no marca conexion exitosa
    end
```

Cuando batView presiona `Reconectar`, vuelve a abrir el puerto serial y envia:

```text
PC: #CONNECTION
```

El ESP32 debe responder preferiblemente:

```text
ESP32: #ACK,CONNECTION
```

Si el firmware esta en modo telemetria o acaba de salir de una operacion, batView
tambien acepta:

```text
ESP32: #ACK,DATA
```

Sin embargo, para evitar ambiguedades, se recomienda que el firmware haga esto
cuando recibe `#CONNECTION`:

1. Pausar temporalmente el envio de telemetria.
2. Responder `#ACK,CONNECTION`.
3. Enviar opcionalmente `#STATUS,CONNECTED,ESP32_READY`.
4. Esperar el siguiente comando del PC.

Flujo ideal:

```text
PC:    #CONNECTION
ESP32: #ACK,CONNECTION
ESP32: #STATUS,CONNECTED,ESP32_READY
```

## 7. Timeouts y reintentos de batView

Durante conexion:

- batView abre el puerto serial.
- Envia `#CONNECTION`.
- Espera hasta 6 segundos por una respuesta valida.
- Reenvia `#CONNECTION` aproximadamente cada 1.2 segundos mientras espera.
- Acepta como conexion valida:
  - `#ACK,CONNECTION`
  - `#ACK,CONECTION`
  - `#ACK,DATA`
  - `#STATUS,...` con `ESP32_READY` o `CONNECTED`, pero en ese caso reintenta el
    handshake enviando de nuevo `#CONNECTION`.

Para comandos normales:

- batView espera el ACK correspondiente.
- Si llega `#ERROR,...`, el comando falla.
- Si llega un ACK distinto al esperado, batView lo ignora y sigue esperando el
  ACK correcto hasta timeout.

## 8. Resumen rapido para firmware

### 8.1 Diagrama de decision del firmware

```mermaid
flowchart TD
    A["Recibir linea serial"] --> B{"Empieza con #?"}
    B -- "No" --> X["Ignorar o responder #ERROR,INVALID_FRAME,..."]
    B -- "Si" --> C{"Comando"}

    C -- "#CONNECTION" --> D["Responder #ACK,CONNECTION"]
    D --> D2["Opcional: #STATUS,CONNECTED,ESP32_READY"]

    C -- "#Battery,..." --> E{"Parametros validos?"}
    E -- "Si" --> E1["Guardar perfil"]
    E1 --> E2["Responder #ACK,Battery"]
    E -- "No" --> E3["Responder #ERROR,INVALID_VALUE,..."]

    C -- "#LOAD,<0-100>" --> F["Responder #ACK,LOAD"]
    F --> F1["Iniciar carga"]
    F1 --> T["Enviar #DATA periodicamente"]

    C -- "#UNLOAD,<0-100>" --> G["Responder #ACK,UNLOAD"]
    G --> G1["Iniciar descarga"]
    G1 --> T

    C -- "#CICLE,0,0 o #CICLE,1,n" --> H["Responder #ACK,CICLE"]
    H --> H1["Iniciar ciclado"]
    H1 --> T

    C -- "#STOP" --> I["Detener operacion"]
    I --> I1["Responder #ACK,STOP"]
    I1 --> I2["Opcional: #STATUS,STOPPED,USER_STOP"]

    C -- "Otro" --> J["Responder #ERROR,INVALID_COMMAND,..."]
```

Implementar como minimo:

```text
Si recibe #CONNECTION:
    responder #ACK,CONNECTION

Si recibe #Battery,...:
    validar parametros
    responder #ACK,Battery o #ERROR,...

Si recibe #LOAD,<0-100>:
    responder #ACK,LOAD
    iniciar carga
    enviar #DATA,...

Si recibe #UNLOAD,<0-100>:
    responder #ACK,UNLOAD
    iniciar descarga
    enviar #DATA,...

Si recibe #CICLE,0,0 o #CICLE,1,<cycleCount>:
    responder #ACK,CICLE
    iniciar ciclado
    enviar #DATA,...

Si recibe #STOP:
    detener operacion
    responder #ACK,STOP
```

Regla mas importante: para `#CONNECTION`, responder siempre
`#ACK,CONNECTION`, incluso si el ESP32 ya estaba conectado o enviando datos.

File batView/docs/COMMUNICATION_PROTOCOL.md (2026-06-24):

# PC <-> ESP32 Communication Protocol

batView communicates with the ESP32 over USB serial using newline-terminated text frames.

## Serial Settings

- Baud rate: `115200`
- Format: `8N1`
- Flow control: none
- Each frame starts with `#`
- Each frame is sent as one line, ending with `\n`

## PC to ESP32

The PC sends these commands:

```text
#CONNECTION
#Battery,<BatteryNameID>,<V@max>,<V@min>,<Amax>
#CICLE,0,0
#CICLE,1,<cycleCount>
#LOAD,<targetPercent>
#UNLOAD,<targetPercent>
#STOP
```

Notes:

- `BatteryNameID` must not contain commas.
- `V@max`, `V@min`, and `Amax` are decimal numbers.
- `V@min` must be lower than `V@max`.
- `targetPercent` is an integer from `0` to `100`.
- `#CICLE,0,0` means indefinite cycle mode.
- `#CICLE,1,<cycleCount>` means a fixed number of cycles.

## ESP32 to PC

For every command, the ESP32 should answer with the matching ACK:

```text
#ACK,CONNECTION
#ACK,Battery
#ACK,CICLE
#ACK,LOAD
#ACK,UNLOAD
#ACK,STOP
```

The app also accepts the legacy typo `#ACK,CONECTION` during connection.

The ESP32 may send status or error frames:

```text
#STATUS,<state>,<detail>
#ERROR,<code>,<message>
```

Telemetry is sent with `#DATA`:

```text
#DATA,<voltage>,<current>,<timestampMs>
#DATA,<voltage>,<current>,<timestampMs>,<state>,<completedCycles>
```

`timestampMs` must be milliseconds from the ESP32. The PC stores the received value and only converts it to seconds for plotting.

## Expected Flow

1. PC opens the serial port and sends `#CONNECTION`.
2. ESP32 answers `#ACK,CONNECTION`.
3. PC sends a battery profile with `#Battery,...`.
4. ESP32 answers `#ACK,Battery`.
5. PC sends `#LOAD,...`, `#UNLOAD,...`, or `#CICLE,...`.
6. ESP32 answers the matching ACK and starts sending `#DATA` frames.
7. PC may send `#STOP`.
8. ESP32 answers `#ACK,STOP` and stops the active operation.

If the ESP32 rejects a command, it should send `#ERROR,<code>,<message>` instead of the ACK.

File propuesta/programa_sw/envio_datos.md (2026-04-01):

# Estipulación de los datos a enviar desde el ESP32

Luego del Start, selección de tipo de batería y función: 

Se envía por medio de comunicación serial: 

```cpp
datos = [batería seleccionada, tipo de batería, función]
```

Donde: 

- Batería seleccionada es un 1 o 0. 
- Tipo de batería, se va a establecer un código para cada tipo batería que soporta el programa.
- función: 
    - 1: Ciclado
    - 2: Carga
    - 3: Descarga
    - 4: Leer datos .csv (aquí el ESP32 no va a hacer nada)

---

Selección de función de Ciclado: 

```cpp
datos = [Tipo de ciclado, cantidad de ciclados]
```
Donde: 
- ``datos[0]``: 
    - 0: Ciclado indefinido, ignora a ``datos[1]`` y espera una nueva señal de stop. 
    - 1: Ciclado definido, toma en cuenta la cantidad de ciclados que se indica en ``datos[1]``.
- ``datos[1]``: Indica la cantidad de ciclados que se quieren llevar a cabo. 

---

Sección de carga: 
Envía: 
```cpp
datos = [% de carga]
```
El porcentaje de carga luego se convierte en el ESP32 y se establece hasta que nivel debe llegar la batería

--- 
Sección de descarga: 
Envía: 
```cpp
datos = [% de descarga]
```
El porcentaje de carga luego se convierte en el ESP32 y se establece hasta que nivel debe llegar la batería

--- 
Leer datos .csv no envía nada.

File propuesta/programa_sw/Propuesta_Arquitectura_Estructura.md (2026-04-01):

# Propuesta de Arquitectura y Estructura del Repositorio  
## Aplicación de monitoreo y adquisición de datos vía ESP32

---

## 1. Introducción

El presente documento describe la arquitectura y la estructura propuesta para el desarrollo de una aplicación de escritorio basada en C++ y wxWidgets en macOS. La aplicación tiene como propósito principal la adquisición, procesamiento, visualización y almacenamiento de datos provenientes de un dispositivo ESP32 mediante comunicación USB (UART).

El sistema contempla:
- Comunicación bidireccional con el dispositivo
- Definición de un protocolo de comunicación propio
- Procesamiento estructurado de datos
- Exportación en formato CSV
- Integración de Python embebido para análisis y graficación
- Interfaz gráfica robusta y modular

---

## 2. Enfoque arquitectónico

Se plantea una arquitectura modular basada en separación de responsabilidades, estructurada en las siguientes capas:

### 2.1 Presentación (UI)
Encargada de la interacción con el usuario mediante wxWidgets. No contiene lógica de negocio ni acceso directo a hardware.

### 2.2 Aplicación (Application Layer)
Coordina los casos de uso del sistema y conecta la interfaz con los servicios del núcleo.

### 2.3 Núcleo (Core / Domain)
Contiene los modelos, reglas de negocio y definición del protocolo de comunicación.

### 2.4 Infraestructura
Implementa la interacción con elementos externos:
- Comunicación serial
- Sistema de archivos
- Exportación CSV
- Motor Python embebido
- Configuración
- Registro de eventos (logging)

---

## 3. Estructura del repositorio

```text
repo/
├── docs/
├── config/
├── python/
│   └── embedded/
├── tests/
├── src/
│   ├── app/
│   ├── core/
│   │   ├── models/
│   │   ├── protocol/
│   │   └── services/
│   ├── infrastructure/
│   │   ├── serial/
│   │   ├── csv/
│   │   ├── python/
│   │   ├── logging/
│   │   └── config/
│   └── ui/
│       ├── frames/
│       ├── panels/
│       ├── dialogs/
│       └── viewmodels/
├── data/
├── logs/
└── CMakeLists.txt
```

---

## 4. Descripción de componentes

### 4.1 src/main.cpp
Archivo de entrada del sistema. Se limita a:
- Inicialización de la aplicación
- Creación del contexto global
- Lanzamiento de la interfaz principal

---

### 4.2 app/
Contiene la lógica de coordinación global.

- Application: orquestador principal  
- AppContext: contenedor de dependencias  
- AppState: estado global del sistema  

---

### 4.3 core/

#### models/
Define las estructuras de datos principales:
- Measurement  
- Session  
- Command  
- Response  
- DeviceInfo  

#### protocol/
Define el protocolo de comunicación:
- Parseo de mensajes  
- Serialización  
- Validación de tramas  
- Manejo de errores  

#### services/
Contiene los casos de uso:
- DeviceService  
- AcquisitionService  
- SessionService  
- ExportService  
- PlotService  

---

### 4.4 infrastructure/

#### serial/
Gestión de comunicación USB:
- Apertura y cierre de puerto  
- Lectura continua  
- Escritura  
- Descubrimiento de puertos  

#### csv/
Lectura y escritura de archivos CSV.

#### python/
Integración con Python embebido:
- Inicialización del intérprete  
- Ejecución de scripts  
- Conversión de datos  

#### logging/
Registro de eventos del sistema.

#### config/
Carga de configuraciones desde archivos externos.

---

### 4.5 ui/

#### frames/
Ventanas principales.

#### panels/
Componentes reutilizables de la interfaz:
- Conexión  
- Adquisición  
- Visualización  
- Logs  

#### dialogs/
Ventanas auxiliares.

#### viewmodels/
Intermediarios entre la UI y la lógica del sistema.

---

## 5. Flujo de operación

1. La interfaz solicita conexión  
2. Se inicializa el puerto serial  
3. Se reciben datos del ESP32  
4. Se parsean mediante el módulo de protocolo  
5. Se transforman en modelos de datos  
6. Se almacenan en sesión activa  
7. Se exportan a CSV  
8. Se procesan mediante Python  
9. Se actualiza la interfaz gráfica  

---

## 6. Estructura de datos

Formato CSV sugerido:

```text
timestamp,sequence,channel,voltage,current,temperature,status,raw_frame
```

Estructura de almacenamiento:

```text
data/exports/
└── session_x/
    ├── raw_data.csv
    ├── processed_data.csv
    ├── metadata.json
    └── plots/
```

---

## 7. Integración con Python

Los scripts se organizan en:

```text
python/embedded/
```

Ejemplos:
- plotter.py  
- filters.py  
- transforms.py  

---

## 8. Configuración

Archivo base:

```json
{
  "serial": {
    "baudrate": 115200,
    "timeout_ms": 200
  },
  "paths": {
    "exports_dir": "./data/exports"
  }
}
```

---

## 9. Pruebas

Tipos de pruebas:

- Unitarias: parseo, modelos, CSV  
- Integración: flujo completo de datos  
- Protocolo: validación de tramas  

---

## 10. Documentación

Ubicada en `docs/`:

- architecture.md  
- protocol.md  
- data-format.md  

---

## 11. Conclusión

La estructura planteada permite una separación clara de responsabilidades, facilitando la escalabilidad, mantenibilidad y robustez del sistema. La organización modular asegura que cada componente evolucione de manera independiente, manteniendo una base sólida para futuras extensiones.

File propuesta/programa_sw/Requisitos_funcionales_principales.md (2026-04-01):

# Requisitos Funcionales Principales del Software 

En el presente apartado se espera describir lo que son los requisitos funcionales para el software.

---
## - ¿Qué puede hacer el usuario en el sistema?

    - El usuario debe tener la posibilidad de seleccionar el tipo de batería con la que se está trabajando, se plantea la opción de baterías de 12V, 1,5V y 1,2V.
    - Se debe de poder seleccionar entre ::
---
## - ¿Qué procesos debe ejecutar la aplicación?

---
## - ¿Qué datos debe registrar, consultar, modificar o eliminar?

---
## - ¿Qué respuestas debe dar ante ciertas acciones?

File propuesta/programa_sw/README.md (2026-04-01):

# Propuesta para el Software y visualización/control de datos

[Propuesta Final del Sistema](Propuesta_Arquitectura_Estructura.md)

## Objetivo del sistema

Desarrollar una aplicación de software orientada a la adquisición, visualización y análisis de datos provenientes de un sistema de gestión de baterías (BMS) mediante un protocolo de comunicación definido, que permita:
- Visualizar variables eléctricas y operativas en tiempo real mediante gráficas y medidores.
- Controlar y configurar modos de operación para carga, descarga y ciclado de baterías.
- Seleccionar y parametrizar distintos tipos de baterías según sus características nominales.
- Exportar e importar datos en formatos estándar (CSV, MAT, XLSX) para análisis posterior.
- Estimar y mostrar indicadores de estado de la batería, incluyendo State of Health (SoH). El cálculo y los diversos aspectos necesarios se verán estipulados por el grupo asociado al ciclador.

## Usuario Objetivo

El sistema está orientado a usuarios que requieran estudiar y analizar el comportamiento de baterías, tales como estudiantes, investigadores o personal técnico en laboratorio.
La aplicación permitirá monitorear variables eléctricas relevantes, controlar parámetros operativos de carga y descarga, y evaluar indicadores de vida útil. Asimismo, brindará la posibilidad de analizar datos históricos previamente almacenados para realizar estudios comparativos o evaluaciones de degradación.

## Problemas que resuelve

Actualmente, el estudio y monitoreo de baterías en entornos académicos o de laboratorio suele depender de herramientas fragmentadas, interfaces limitadas del propio ciclador o procesamiento manual de datos, lo que genera las siguientes problemáticas:
- Falta de visualización integrada en tiempo real: Las variables eléctricas (voltaje, corriente, temperatura, capacidad, etc.) no siempre pueden observarse de forma centralizada y dinámica.
- Limitado control parametrizable: La configuración de modos de carga, descarga o ciclado puede estar restringida a interfaces poco flexibles o no adaptadas a distintos tipos de batería.
- Dificultad para estimar el estado de salud (SoH): La evaluación de degradación suele requerir procesamiento externo o cálculos manuales, reduciendo la trazabilidad del análisis.
- Procesamiento manual de datos históricos: La manipulación de archivos experimentales sin una herramienta dedicada incrementa el riesgo de errores y dificulta la comparación entre ensayos.
- Falta de estandarización en exportación y análisis: La ausencia de formatos estructurados o compatibles con herramientas de análisis técnico limita la reproducibilidad de resultados.
- El sistema propuesto centraliza la adquisición, control y análisis de datos en una única plataforma, mejorando la trazabilidad experimental, reduciendo errores operativos y facilitando estudios comparativos de desempeño y degradación de baterías.

## Contexto de uso 

El sistema está diseñado para operar en entornos académicos, de investigación o laboratorio técnico donde se realicen pruebas controladas de carga, descarga y ciclado de baterías mediante un sistema de gestión de baterías (BMS) o ciclador compatible.
La aplicación funcionará como interfaz de supervisión y control, comunicándose con el hardware a través de un protocolo de comunicación previamente definido. Su uso está orientado a pruebas experimentales en condiciones controladas y no contempla, en esta etapa, aplicaciones industriales de alta potencia ni integración directa en sistemas críticos de producción.
El software será utilizado en equipos de cómputo convencionales y dependerá de la correcta configuración del sistema de adquisición y comunicación con el dispositivo externo.
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

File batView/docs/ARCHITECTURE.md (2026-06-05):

# Arquitectura

## Visión general

batView está organizado en capas para separar interfaz, lógica de protocolo e infraestructura de hardware.

```text
UI -> ViewModel -> Services -> Protocol / Models -> Infrastructure
```

## Capas

### UI

Responsable de:

- eventos de usuario
- layout y navegación
- presentación del estado
- tráfico visible de mensajes

Archivos principales:

- `src/ui/BatViewApp.cpp`
- `src/ui/frames/MainFrame.cpp`
- `src/ui/panels/ConnectionPanel.cpp`
- `src/ui/dialogs/ExportDialog.cpp`
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

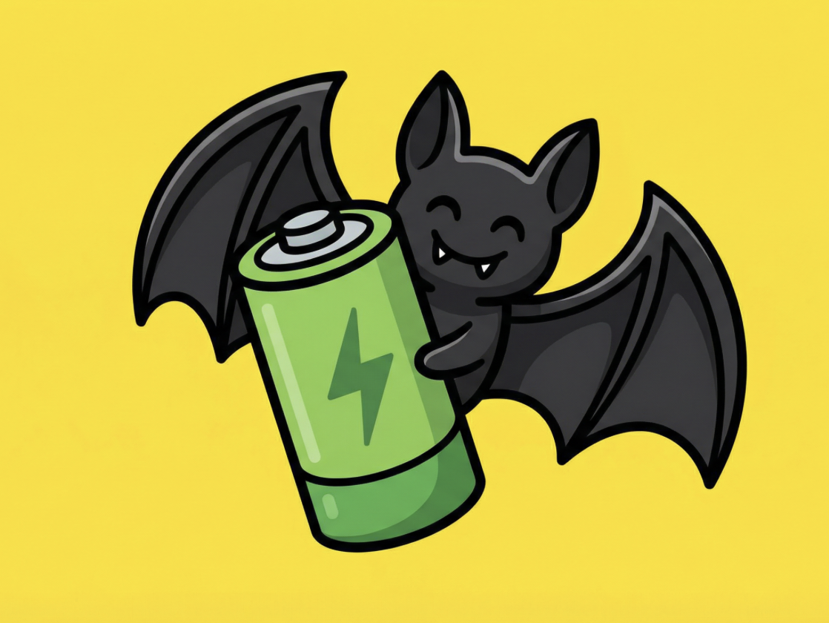
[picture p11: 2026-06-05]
batView/assets/BatView.png

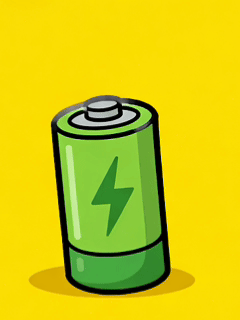
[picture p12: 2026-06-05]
batView/assets/batView.gif

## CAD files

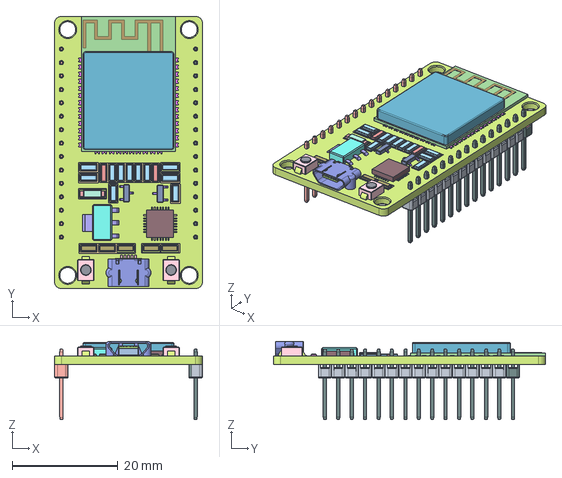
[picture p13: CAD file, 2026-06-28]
PCB/3dmodels/ESP32 dev Kit v1.step
28.0 x 51.5 x 14.8 mm

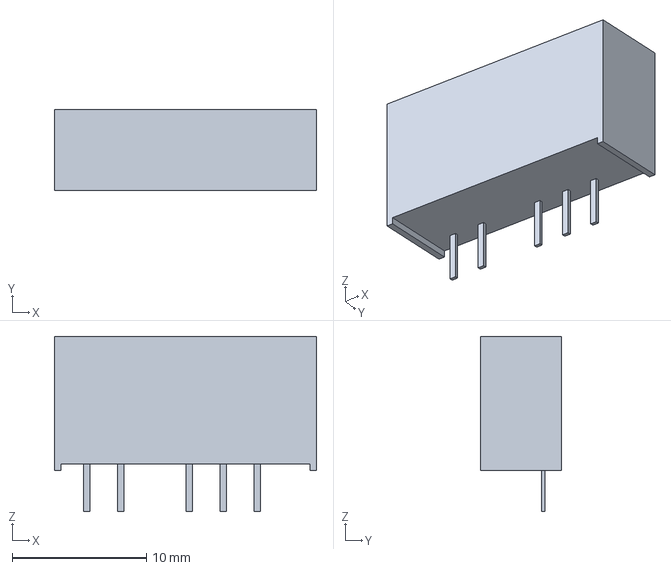
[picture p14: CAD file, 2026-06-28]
PCB/3dmodels/TBA_1-0521E.step
19.5 x 6.00 x 13.1 mm

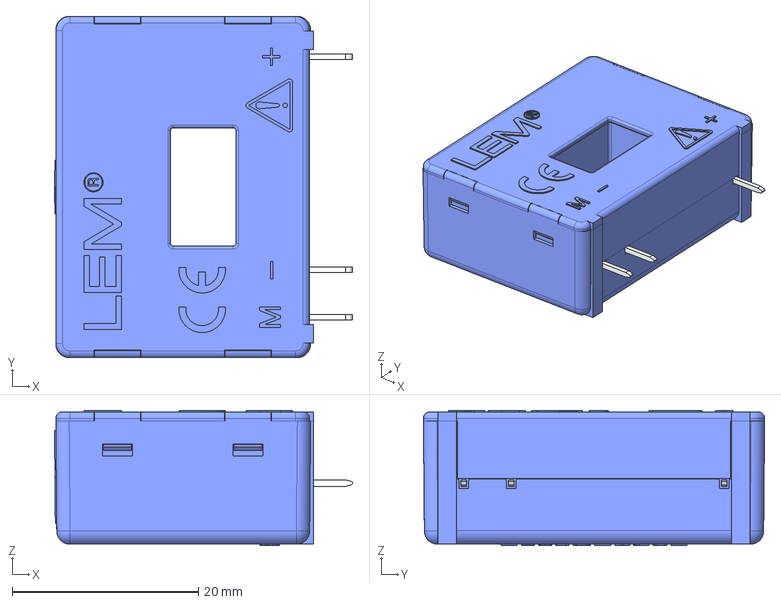
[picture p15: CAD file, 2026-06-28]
PCB/3dmodels/LA_25_P.stp
32.0 x 36.6 x 14.5 mm

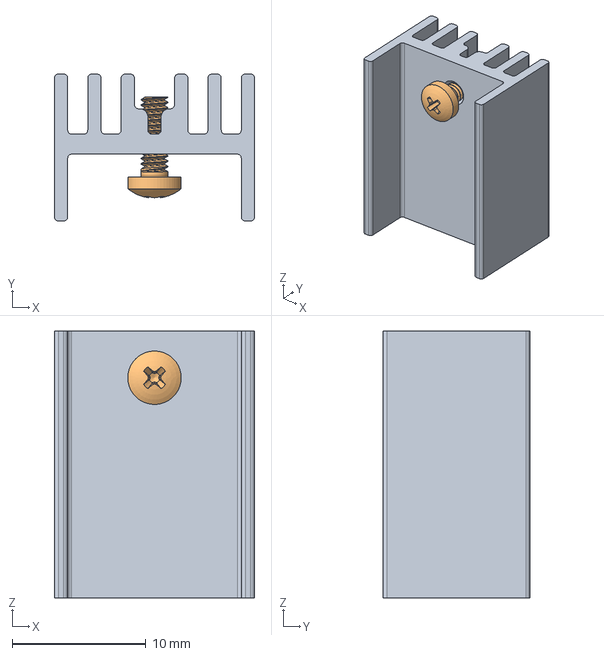
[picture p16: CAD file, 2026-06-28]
PCB/3dmodels/HeatsinkTO220.step
15.0 x 11.0 x 20.0 mm
HeatSink
M2x6-Screw

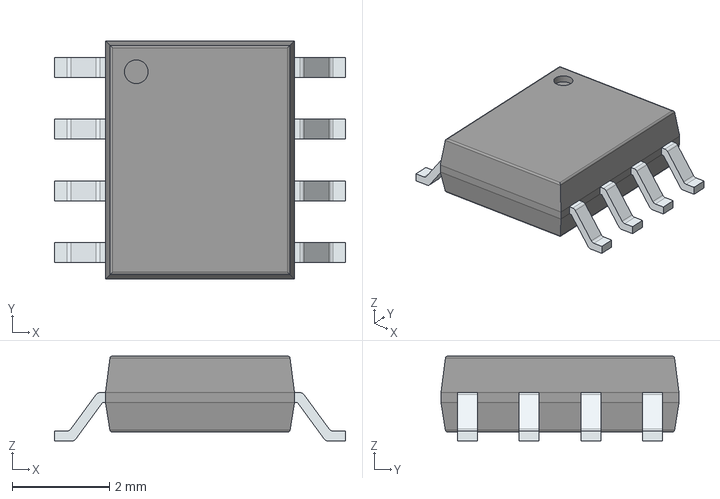
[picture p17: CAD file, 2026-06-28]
PCB/3dmodels/LF353DR.stp
6.00 x 4.91 x 1.75 mm
PinsArrayLR

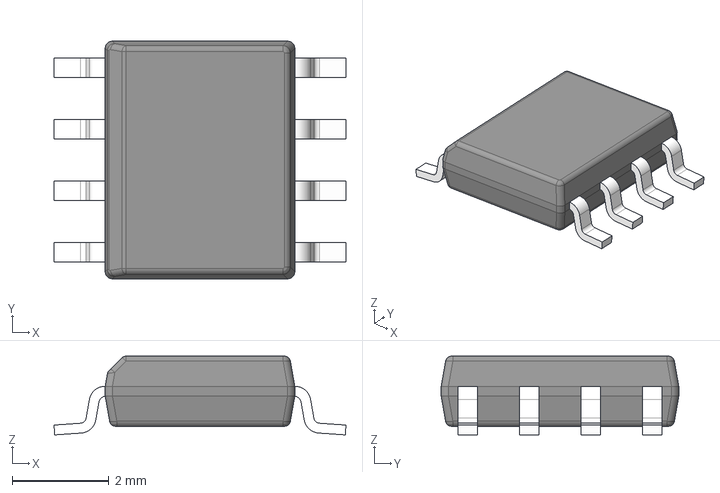
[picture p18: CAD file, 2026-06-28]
PCB/3dmodels/LM358BAIDR.stp
6.02 x 4.90 x 1.63 mm
BODY-SO
LEAD-D0008A x 8

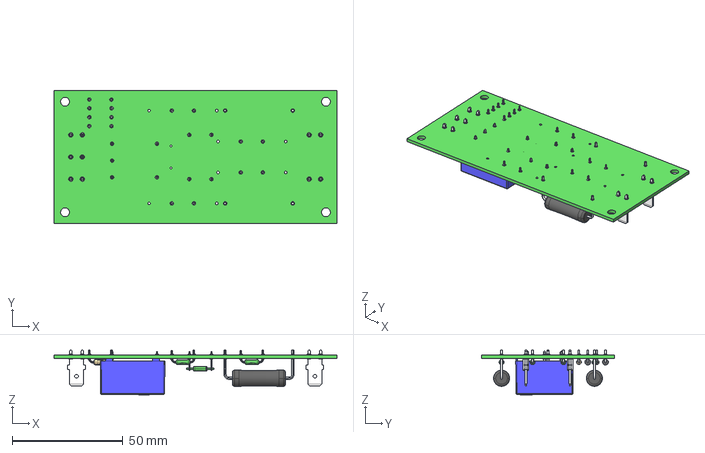
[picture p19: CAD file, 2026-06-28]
PCB/3dmodels/90.28.44.000.0_20191120.stp
128.0 x 60.0 x 20.2 mm

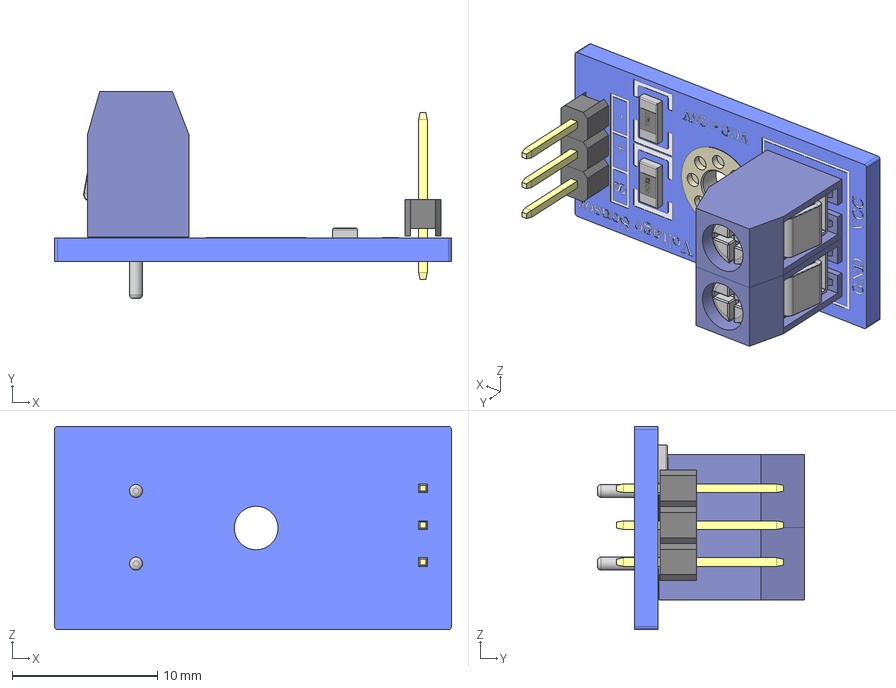
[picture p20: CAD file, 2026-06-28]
PCB/3dmodels/Arduino voltage sensor v1.step
27.3 x 14.2 x 14.0 mm
HEADER10P
ConnectorBody x 2
Wire Socket x 2
Set Screw x 2
Wire Tension Clip x 2

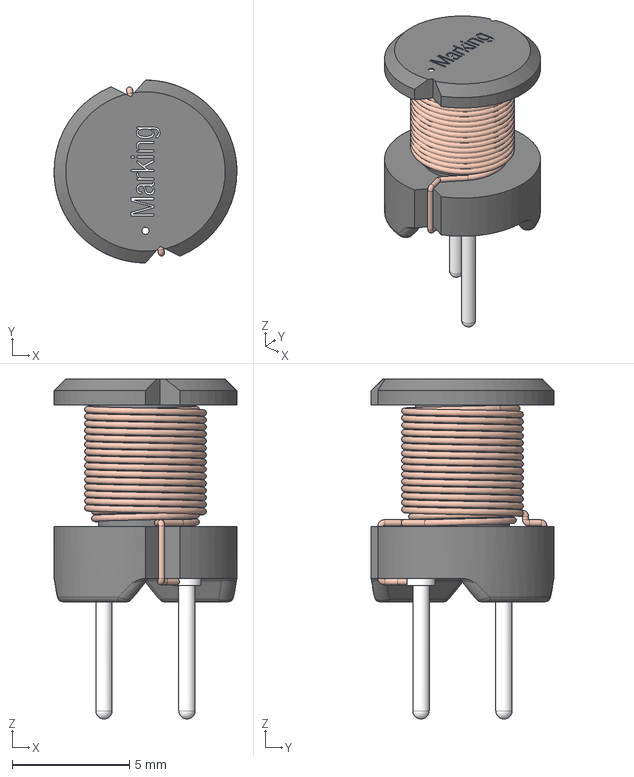
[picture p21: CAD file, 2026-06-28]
PCB/3dmodels/7447720100.stp
7.80 x 7.80 x 14.5 mm
Kern x 2
Pin x 2

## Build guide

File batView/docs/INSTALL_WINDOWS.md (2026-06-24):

# Windows Installation From Zero

Use this guide if your computer runs Windows and you do not have Git,
CMake, Python, Visual Studio Build Tools, or batView installed yet.

The expected result is:

- batView installed at `%LOCALAPPDATA%\batView\batView.exe`.
- A Desktop shortcut named `batView.lnk`.
- Local build files in the project folder under `build-release\`.

## Step 1: Open PowerShell

Open `PowerShell` as a normal user.

You can find it from the Start menu by searching for `PowerShell`.

## Step 2: Check That `winget` Works

batView uses `winget` to install Windows tools automatically.

Run:

```powershell
winget --version
```

If you see a version number, continue to the next step.

If Windows says that `winget` is not recognized:

1. Open the Microsoft Store.
2. Search for `App Installer`.
3. Install or update `App Installer`.
4. Close PowerShell.
5. Open PowerShell again and run `winget --version` one more time.

## Step 3: Install Git

Git is needed first because it downloads the batView source code.

Run:

```powershell
winget install --id Git.Git --exact --silent --accept-package-agreements --accept-source-agreements
```

If `winget` complains about `msstore` but says Git was found in the `winget`
source, run the same command with `--source winget`:

```powershell
winget install --id Git.Git --exact --source winget --silent --accept-package-agreements --accept-source-agreements
```

When the command finishes, close PowerShell and open it again so Windows
refreshes the terminal PATH.

Confirm Git is available:

```powershell
git --version
```

If `git` is still not recognized, add Git to the Windows PATH manually.

### Add Git to PATH manually

1. Open the Start menu.
2. Search for `Environment Variables`.
3. Click `Edit the system environment variables`.
4. In the `System Properties` window, click `Environment Variables...`.
5. Under `User variables for rodrigo`, select `Path`.
6. Click `Edit`.
7. Click `New`.
8. Add this path:

   ```text
   C:\Program Files\Git\cmd
   ```

9. Click `OK` on each window to save the changes.
10. Close PowerShell.
11. Open PowerShell again.
12. Run:

```powershell
git --version
```

If Git was installed somewhere else, first find `git.exe` and add the folder
that contains it. The usual Git path is `C:\Program Files\Git\cmd\git.exe`.

## Step 4: Download batView

Choose where you want to keep the project. This example uses your Documents
folder.

Run:

```powershell
cd $env:USERPROFILE\Documents
git clone https://github.com/roi-ri/proyecto_electrico.git
cd .\proyecto_electrico\batView
```

You must be inside the `batView` folder before running the install script.

To confirm you are in the correct folder, run:

```powershell
dir
```

You should see files such as:

- `install_windows.ps1`
- `build_app.ps1`
- `CMakeLists.txt`
- `src`
- `docs`

## Step 5: Run the batView Installer

From the `batView` folder, run:

```powershell
powershell -ExecutionPolicy Bypass -File .\install_windows.ps1
```

The script installs or prepares:

1. Git, if needed.
2. CMake.
3. Python 3.13.
4. Visual Studio 2022 Build Tools with the C++ workload.
5. `vcpkg` inside `tools\vcpkg`.
6. `wxWidgets` for the detected Windows architecture through `vcpkg`.
7. batView itself.

On ARM64 Windows, the installer detects the ARM64 machine but uses
`x64-windows` by default. Windows ARM can run x64 apps through emulation, and
this avoids requiring a native ARM64 Visual Studio toolchain. The vcpkg host
triplet is also forced to `x64-windows` so vcpkg does not try to build its
helper tools with an unavailable ARM64 compiler. The installer also uses x64
Python for the embedded Python runtime when building x64. If you explicitly need
a native ARM64 build, use `-Triplet arm64-windows`.

This step can take a while the first time because Visual Studio Build Tools,
wxWidgets, and the C++ build are large.

If the install stops after a failed first attempt, update the project and run it
again:

```powershell
git pull
powershell -ExecutionPolicy Bypass -File .\install_windows.ps1
```

If the failure happened while installing `vcpkg` or `wxWidgets`, you can remove
the partial `tools` folder before trying again:

```powershell
Remove-Item -Recurse -Force .\tools
powershell -ExecutionPolicy Bypass -File .\install_windows.ps1
```

## Step 6: Wait for the Success Message

When everything works, the terminal ends with:

```text
batView full listo.
```

The installer also creates:

- `%LOCALAPPDATA%\batView\batView.exe`
- A Desktop shortcut named `batView.lnk`
- `build-release\` inside the `batView` project folder

If you did not use `-NoRun`, batView opens automatically at the end.

## Optional: Install Without Opening batView

If you want to install batView but not open it automatically, run:

```powershell
powershell -ExecutionPolicy Bypass -File .\install_windows.ps1 -NoRun
```

## Optional: Run Again After Everything Is Installed

If Visual Studio Build Tools, CMake, Python, Git, `vcpkg`, and wxWidgets are
already installed or prepared, you can skip dependency installation:

```powershell
powershell -ExecutionPolicy Bypass -File .\install_windows.ps1 -SkipDeps
```

To skip dependencies and also avoid opening the app:

```powershell
powershell -ExecutionPolicy Bypass -File .\install_windows.ps1 -SkipDeps -NoRun
```

To force a specific vcpkg target architecture, use `-Triplet`. The default is
`x64-windows`, including on Windows ARM:

```powershell
powershell -ExecutionPolicy Bypass -File .\install_windows.ps1 -Triplet arm64-windows
powershell -ExecutionPolicy Bypass -File .\install_windows.ps1 -Triplet x64-windows
```

## Optional: Update batView Later

Open PowerShell and go back to the project:

```powershell
cd $env:USERPROFILE\Documents\proyecto_electrico\batView
git pull
powershell -ExecutionPolicy Bypass -File .\install_windows.ps1
```

## Uninstall

To remove the local batView install, Desktop shortcut, generated build files,
Python runtime cache, and the project-local `tools` folder, run this from the
`batView` folder:

```powershell
powershell -ExecutionPolicy Bypass -File .\install_windows.ps1 -Uninstall
```

This does not remove Visual Studio Build Tools, CMake, Python, Git, or
`winget`.

## Common Problems

- `winget` is not recognized: install or update `App Installer` from the
  Microsoft Store, close PowerShell, and open it again.
- `winget` fails with `Failed when searching source: msstore`: rerun the
  command with `--source winget`, for example
  `winget install --id Git.Git --exact --source winget --silent --accept-package-agreements --accept-source-agreements`.
- `Unable to find a valid Visual Studio instance`: Visual Studio Build Tools
  did not install correctly. Run `git pull`, remove the partial `tools` folder
  with `Remove-Item -Recurse -Force .\tools`, and run
  `powershell -ExecutionPolicy Bypass -File .\install_windows.ps1` again.
- `Unable to find a valid toolchain for requested target architecture arm64`:
  use the default `x64-windows` build instead of forcing `arm64-windows`. Run
  `git pull`, remove the partial `tools` folder with
  `Remove-Item -Recurse -Force .\tools`, and run
  `powershell -ExecutionPolicy Bypass -File .\install_windows.ps1` again.
- `git` is not recognized after installing it: close PowerShell and open a new
  PowerShell window. If it still fails, add `C:\Program Files\Git\cmd` to your
  user `Path` environment variable, then reopen PowerShell.
- `.\install_windows.ps1 does not exist`: you are not inside the `batView`
  folder. Run `cd $env:USERPROFILE\Documents\proyecto_electrico\batView`.
- Python link errors mention `pythonXY.lib`: install Python from python.org or
  with `winget install --id Python.Python.3.13 --exact`; do not rely only on
  the Microsoft Store Python app alias.
- `No se encontro Python para compilar`: run `git pull` and try the installer
  again. The installer refreshes PATH and also searches the usual Python install
  folders directly. On Windows ARM, the default x64 build needs x64 Python; if
  it still fails, close PowerShell, open a new PowerShell window, and run the
  installer again. The installer checks Python architecture from the executable
  itself so x64 Python running on Windows ARM is accepted correctly.
- `Could NOT find wxWidgets`: run the installer without `-SkipDeps` so it can
  install `wxwidgets:x64-windows` through `vcpkg`.
- Visual Studio or C++ compiler errors: rerun the installer without
  `-SkipDeps` so it can install Visual Studio 2022 Build Tools with the C++
  workload.

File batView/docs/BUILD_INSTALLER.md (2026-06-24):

# Build and Installer Scripts

This page is now an index. Use the guide for your operating system:

- [macOS installation](./INSTALL_MACOS.md)
- [Linux installation](./INSTALL_LINUX.md)
- [Windows installation](./INSTALL_WINDOWS.md)

## Clean Generated Artifacts

If you want to remove what the build scripts generated and start over, run:

```bash
./build_app.sh --clean
```

On Windows:

```powershell
powershell -ExecutionPolicy Bypass -File .\build_app.ps1 --clean
```

This removes `build-release/`, `dist/`, `python/runtime/`, and the Desktop launcher or bundle created for the current OS.

## Build Scripts

The install scripts call the build scripts after preparing dependencies:

```bash
./build_app.sh
```

```powershell
powershell -ExecutionPolicy Bypass -File .\build_app.ps1
```

Use the build scripts directly only when the tools are already installed.

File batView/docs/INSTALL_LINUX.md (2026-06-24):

# Linux Installation

Use this guide only if your computer runs Linux.

## If Nothing Is Installed

Install these first:

1. CMake.
2. A C++ compiler and build tools.
3. wxWidgets development files.
4. GTK development files.
5. Python 3.
6. Python headers.
7. pip.
8. Packaging helpers such as `dpkg-dev`, `fakeroot`, or `zip`.

On Ubuntu or Debian:

```bash
sudo apt update
sudo apt install -y cmake g++ make pkg-config libwxgtk3.2-dev libgtk-3-dev python3 python3-dev python3-pip dpkg-dev fakeroot zip
```

On Fedora:

```bash
sudo dnf install -y cmake gcc-c++ make pkgconf-pkg-config wxGTK-devel gtk3-devel python3 python3-devel python3-pip rpm-build zip
```

On Arch Linux:

```bash
sudo pacman -S --needed cmake gcc make pkgconf wxwidgets-gtk3 gtk3 python python-pip zip
```

Then run the installer script from the `batView` folder:

```bash
./install_linux.sh
```

If you do not want the app to open at the end, run:

```bash
./install_linux.sh --no-run
```

## If Everything Is Installed

If CMake, the compiler, wxWidgets, GTK, Python, and the packaging helpers are already installed, you can skip the dependency step.

Run:

```bash
./install_linux.sh --skip-deps
```

If you also do not want the app to open, use:

```bash
./install_linux.sh --skip-deps --no-run
```

## What You Should See

When it works, the script ends with `batView full listo.` and creates a Desktop launcher named `batView.desktop`.

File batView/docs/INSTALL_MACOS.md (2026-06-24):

# macOS Installation

Use this guide only if your computer is a Mac.

## If Nothing Is Installed

Install these first:

1. Apple Command Line Tools.
2. Homebrew.
3. `cmake`.
4. `wxwidgets`.
5. `python`.
6. `pkg-config`.

How to install them:

```bash
xcode-select --install
```

After the Apple installer finishes, install Homebrew if you do not already have it:

```bash
/bin/bash -c "$(curl -fsSL https://raw.githubusercontent.com/Homebrew/install/HEAD/install.sh)"
```

Then install the build tools:

```bash
brew install cmake wxwidgets python pkg-config
```

Now run the installer script from the `batView` folder:

```bash
./install_macos.sh
```

If you do not want the app to open at the end, run:

```bash
./install_macos.sh --no-run
```

## If Everything Is Installed

If Apple Command Line Tools, Homebrew, CMake, wxWidgets, Python, and pkg-config are already installed, you can skip the dependency step.

Run:

```bash
./install_macos.sh --skip-deps
```

If you also do not want the app to open, use:

```bash
./install_macos.sh --skip-deps --no-run
```

## What You Should See

When it works, the script ends with `batView full listo.` and the app appears on the Desktop as `batView.app`.

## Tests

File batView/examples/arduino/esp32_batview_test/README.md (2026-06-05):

# ESP32 batView Test Sketch

This folder contains a minimal Arduino IDE sketch for an ESP32 that speaks the serial protocol expected by batView.

Files:
- [esp32_batview_test.ino](/Users/rodrigo/Documents/UCR/Proyecto_Electrico/proyecto_electrico/batView/examples/arduino/esp32_batview_test/esp32_batview_test.ino)

## Upload Steps

1. Open Arduino IDE.
2. Open `examples/arduino/esp32_batview_test/esp32_batview_test.ino`.
3. Select your ESP32 board.
4. Select the correct serial port.
5. Upload the sketch.
6. Open batView and connect to the same port at `115200`.

## What batView Should See

- On connect, batView sends `#CONNECTION`.
- The ESP32 replies with `#ACK,CONNECTION`.
- After `#Battery,...`, `#LOAD,...`, `#UNLOAD,...`, `#CICLE,...`, and `#STOP`, the ESP32 replies with the expected `#ACK,...`.
- While `LOAD`, `UNLOAD`, or `CICLE` is active, batView should receive periodic `#DATA,...` frames.

## How To Test Missing ACK

Edit the booleans at the top of the sketch:

- Set `SEND_ACK_CONNECTION = false` to test the explicit connection timeout message.
- Set `SEND_ACK_BATTERY = false` to test battery profile selection without ACK.
- Set `SEND_ACK_LOAD = false` to test missing `#ACK,LOAD`.
- Set `SEND_ACK_UNLOAD = false` to test missing `#ACK,UNLOAD`.
- Set `SEND_ACK_CICLE = false` to test missing `#ACK,CICLE`.

Then upload again and retry from batView.

## How To Test ESP32 Error Frames

Set one of these to `true`:

- `SEND_ERROR_ON_BATTERY`
- `SEND_ERROR_ON_LOAD`
- `SEND_ERROR_ON_UNLOAD`
- `SEND_ERROR_ON_CICLE`
- `SEND_ERROR_ON_STOP`

batView should display the explicit `#ERROR,...` reason returned by the sketch.

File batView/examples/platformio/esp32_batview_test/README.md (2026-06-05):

# PlatformIO ESP32 Upload

This is the PlatformIO version of the batView ESP32 test sketch.

Files:
- [platformio.ini](/Users/rodrigo/Documents/UCR/Proyecto_Electrico/proyecto_electrico/batView/examples/platformio/esp32_batview_test/platformio.ini)
- [src/main.cpp](/Users/rodrigo/Documents/UCR/Proyecto_Electrico/proyecto_electrico/batView/examples/platformio/esp32_batview_test/src/main.cpp)

## Current Port

The config is pre-filled with:

- `/dev/cu.usbserial-0001`

If your ESP32 appears on a different port, update `upload_port` and `monitor_port` in `platformio.ini`.

## Install PlatformIO Core

If you want the CLI version:

```bash
python3 -m pip install --user platformio
```

If `pio` still is not found after install, use:

```bash
python3 -m platformio --version
```

## Build

From this folder:

```bash
cd /Users/rodrigo/Documents/UCR/Proyecto_Electrico/proyecto_electrico/batView/examples/platformio/esp32_batview_test
python3 -m platformio run
```

## Upload

```bash
cd /Users/rodrigo/Documents/UCR/Proyecto_Electrico/proyecto_electrico/batView/examples/platformio/esp32_batview_test
python3 -m platformio run --target upload
```

## Serial Monitor

```bash
cd /Users/rodrigo/Documents/UCR/Proyecto_Electrico/proyecto_electrico/batView/examples/platformio/esp32_batview_test
python3 -m platformio device monitor
```

## If Upload Fails

- Confirm the correct board is selected in `platformio.ini`.
- If your board is not a generic ESP32 dev board, change:

```ini
board = esp32dev
```

to the correct PlatformIO board id for your hardware.

- Try pressing and holding `BOOT`, then run upload, and release `BOOT` when the upload starts.
- Make sure the cable supports data, not only power.
- Close any app that may already be using the serial port.

## Test Missing ACK

Edit the booleans at the top of `src/main.cpp`:

- `SEND_ACK_CONNECTION = false`
- `SEND_ACK_BATTERY = false`
- `SEND_ACK_LOAD = false`
- `SEND_ACK_UNLOAD = false`
- `SEND_ACK_CICLE = false`

Then rebuild and upload again.

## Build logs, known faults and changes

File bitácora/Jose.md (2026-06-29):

# Bitácora del Proyecto Eléctrico

Jose Manuel Solis

Sistema Electrónico para Ciclado y Evaluación de Vida Útil de Baterías

## Objetivos

### Objetivo General

Diseñar e implementar un sistema integral de ciclado de baterías basado en una tarjeta de circuito impreso y controlado mediante un microcontrolador ESP32, capaz de realizar procesos programables de carga y descarga, monitorear y registrar variables eléctricas relevantes para la estimación del estado de la batería y su vida útil, e integrarse con una interfaz de usuario en computadora que permita la selección del tipo de batería, configuración de parámetros de operación y análisis del comportamiento a lo largo de múltiples ciclos.

### Objetivos Específicos

- Diseñar una placa de circuito impreso (PCB) para el ciclador de baterías, mediante la construcción y simulación de circuitos eléctricos en KiCad y PLECS, con el fin de implementar un sistema capaz de realizar procesos programables de carga y descarga, así como medir variables eléctricas relevantes del sistema.
- Diseñar un sistema de comunicación serial entre la PCB del ciclador de baterías y la interfaz gráfica, utilizando un protocolo de comunicación y un microcontrolador, con el fin de establecer un canal de control entre la interfaz de usuario y el hardware del sistema (PCB).
- Diseñar una interfaz gráfica de usuario mediante el lenguaje C++ y la librería WxWidgets, con el fin de permitir la configuración de parámetros de operación, la selección del tipo de batería y el monitoreo de variables durante los ciclos de carga y descarga.

## Entregables

- Repositorio de GitHub.
- PCB funcional.
- Manual de instalación de interfaz gráfica.
- Prototipos y sistema final implementado.

> Nota: En este proyecto se forma parte del subgrupo encargado del diseño electrónico, el diseño del sistema de control y el hardware del sistema PCB.

## 1. Semana 1

### 1.1. Reunión con Mauricio

**Fecha:** 9 de Marzo, 2026

**Horas:** De 10 a.m. a 11:30 a.m. (1 hora y 30 minutos)

#### Objetivos

- Presentarle el proyecto al profesor Mauricio Espinoza, comentar la división que se va a implementar, las partes y el prototipo final que se quiere entregar.

#### Actividades y Resultados

- Se realizó una reunión en Zoom con el profesor Mauricio para presentarle la propuesta del proyecto que se desea realizar.

#### Comentarios

- El profesor acepta la propuesta y brinda ideas de lo que él espera como prototipo final del proyecto.

### 1.2. Reunión de diseño conceptual del prototipo con los compañeros

**Fecha:** 9 de marzo, 2026

**Horas:** De 7 p.m. a 10 p.m. (3 horas)

#### Objetivos

- Presentar y discutir las ideas del grupo, así como desarrollar un esquema preliminar del modelo a implementar.

#### Actividades y Resultados

- Se expuso la idea de hacer un ciclador de baterías el cual se pueda conectar a la computadora y obtener datos de la batería.
- Se propuso dividir el proyecto en 3 secciones: la PCB y el sistema de control, el protocolo de comunicación y la interfaz gráfica.
- Se proponen 3 metas claras: que se pueda ciclar la batería, que se pueda cargar o descargar completamente y que se pueda cargar o descargar de un porcentaje a otro; en todos los casos obteniendo datos para calcular la vida útil y la capacidad de carga de la batería.
- Se hizo un dibujo para organizar las ideas de cómo debe funcionar el prototipo.

#### Comentarios

- Queda pendiente definir el microcontrolador. Las dos opciones que se tienen son el C2000 de Texas Instruments o el ESP32.

### 1.3. Diseño del circuito de ciclado

**Fecha:** 10 de Marzo, 2026

**Horas:** De 1 p.m. a 5 p.m. (4 horas)

#### Objetivos

- Diseñar el circuito y el lazo de control que se encargue de ciclar la batería.

#### Actividades y Resultados

- Se diseñó un circuito basado en una etapa de salida de cargas con el fin de que los transistores se encarguen de controlar la corriente de la batería, la cual se cataloga como la perturbación al cargar y descargar la batería.
- Se plasma una idea de un lazo de control de forma que por medio de los amplificadores operacionales se pueda encender y apagar los transistores.

#### Comentarios

- Falta diseñar bien el lazo de control. Se tiene pensado un lazo de control prealimentado ya que se puede medir la perturbación.

## 2. Semana 2

### 2.1. Reunión con Mauricio para discutir el proyecto

**Fecha:** 16 de Marzo, 2026

**Horas:** De 9 a.m. a 11 a.m. (2 horas)

#### Objetivos

- Comentarle al profesor Mauricio el diseño conceptual que se tiene pensado y proponer utilizar el C2000 como microcontrolador.

#### Actividades y Resultados

- Se realizó una reunión con Mauricio en la que se propuso el prototipo planteado.
- El profesor Mauricio nos ayudó a definir las ideas y los entregables del proyecto.
- El profesor nos propuso utilizar el ESP32 por su versatilidad con la comunicación.

#### Comentarios

- El profesor nos enseñó diferentes sensores que podemos tomar en cuenta y aprobó el prototipo presentado.

### 2.2. Simulación del circuito

**Fecha:** 17 de Marzo, 2026

**Horas:** De 1 p.m. a 5 p.m. (4 horas)

#### Objetivos

- Verificar el diseño del circuito pensado anteriormente.
- Simular el circuito y verificar que puede cargar y descargar la batería con la topología utilizada.

#### Actividades y Resultados

- Se definió un lazo de control prealimentado-realimentado, ya que la corriente, que es la perturbación, se puede medir con sensores de corriente. Además, se puede agregar un controlador PI para que se siga mejor la referencia.
- Se simuló el circuito y el lazo de control en PSpice, generando la gráfica del comportamiento de la batería. En la gráfica se puede confirmar que el circuito se comporta como se esperaba, cargando y descargando la batería según se indique en la referencia.

#### Comentarios

- Falta hacer los cálculos de la señal de control para verificar que el circuito sí cumple con las ecuaciones de carga y descarga.

### 2.3. Cálculo de la acción de control

**Fecha:** 11 de Marzo, 2026

**Horas:** De 3 p.m. a 4 p.m. (1 hora)

#### Objetivos

- Calcular la acción de control de la malla de carga y descarga.

#### Actividades y Resultados

- Se hicieron los cálculos correspondientes para identificar la acción de control de cada malla.
- La acción de control dio como se esperaba: el circuito de carga positivo y el de descarga negativo.

#### Comentarios

- Se aseguró que el circuito funciona, por lo que lo próximo es buscar los componentes y diseñar la PCB.

### 2.4. Inicio del diseño de la PCB

**Fecha:** 13 de Marzo, 2026

**Horas:** De 4 p.m. a 7 p.m. (3 horas)

#### Objetivos

- Diseñar el esquemático inicial de la PCB en KiCad para mostrarle al profesor.
- Hacer un esquemático en el que se contemplen todas las entradas y salidas de forma que solo se tengan que colocar los dispositivos como el microcontrolador o los sensores.

#### Actividades y Resultados

- Se hizo todo el esquemático de la PCB contemplando las entradas y salidas.
- Se definieron algunos componentes como resistencias, capacitores e inductores que se definieron previamente en la simulación.

#### Comentarios

- Queda pendiente enseñársela al profesor para la aprobación.
- Queda pendiente definir bien los pines del ESP32 con el equipo de comunicación.
- Falta definir los componentes de la PCB.

## 3. Semana 3

### 3.1. Reunión con el profesor Mauricio

**Fecha:** 23 de Marzo, 2026

**Horas:** De 10 a.m. a 12 m.d. (2 horas)

#### Objetivos

- Resolver dudas sobre el circuito de carga.
- Resolver dudas sobre el sistema de control.
- Mostrarle la PCB para verificar si falta algo o en qué se puede mejorar.

#### Actividades y Resultados

- Se aclaró la duda de la alimentación del circuito de carga, ya que este tiene que tener la fuente de tensión que carga la batería.
- Se resolvió la duda de cómo el sistema de control se encarga de suprimir la perturbación. Además, se aclaró cómo funciona la referencia en las simulaciones, ya que al ser una senoide en la simulación causaba una confusión sobre si había que generar una senoide con el microcontrolador.
- Se mostró la PCB y Mauricio nos recomendó hacer unos cambios, entre ellos utilizar cables directos desde la batería hasta el sensor de tensión solo para medir esta, con el fin de evitar las resistencias parásitas. Otra recomendación fue integrar todos los componentes en una sola PCB, por lo que los convertidores DC-DC se deben acomodar ahí también.
- Se nos recomendó investigar sobre baterías para definir la batería que se va utilizar o las que se van utilizar, con el fin de definir las corrientes y las tensiones del microcontrolador.
- Se recomendó hacer el modelo de la caja en donde se va a meter todo para ordenar la PCB con la posición de los conectores y tener el modelo de cómo conectar la batería.

#### Comentarios

- Queda pendiente diseñar la caja del prototipo antes de seguir con la PCB.
- Se le encarga a Eduardo Rojas hacer la investigación de las baterías para definir el modelo y con eso hacer los cálculos de carga y descarga.
- Se debe investigar para utilizar 4 cables en la batería.
- Queda pendiente investigar sobre sensores LEM y el de tensión, buscar opciones accesibles para tener de dónde elegir cuando se tengan los datos de la batería.

### 3.2. Búsqueda de los componentes electrónicos

**Fecha:** 24 de Marzo, 2026

**Horas:** De 3 p.m. a 7 p.m. (4 horas)

#### Objetivos

- Hacer una lista de los componentes a utilizar, en donde se tenga la hoja de datos, el link de compra y el precio.
- Definir el microcontrolador que se va a utilizar.

#### Actividades y Resultados

- Se buscaron y compararon los componentes que se van a utilizar preliminarmente.
- Se buscaron las características de los microcontroladores C2000 y ESP32.
- Se generó un documento en el que se tienen el componente, la hoja de datos, el precio y el link para comprarlo.
- Se escogió el microcontrolador ESP32 debido a sus características para comunicación. Si bien no es el más dotado para la parte de control, tiene lo que se requiere. Además, cuenta con muchas herramientas para comunicación.

#### Comentarios

- Al utilizar diferentes baterías se requieren diferentes tensiones controladas por medio de la computadora. Por eso se requiere un convertidor DC-DC variable, que se va a hacer comprando un convertidor DC-DC normal y colocándole un trimmer digital en el trimmer que ya viene.
- Esta es una lista preliminar y está sujeta a modificaciones si se requieren más componentes.

### 3.3. Continuación del diseño de la PCB

**Fecha:** 27 de Marzo, 2026

**Horas:** De 3 p.m. a 6 p.m. (3 horas)

#### Objetivos

- Diseñar el modelo 3D de la PCB en KiCad.
- Hacer un modelo 3D de la PCB en el que se puedan colocar sobre pines tipo jack el ESP32 y sensores.
- Hacer una PCB de menos de 10 cm x 10 cm para ahorrar en los costos de fabricación.

#### Actividades y Resultados

- Se hizo el modelo 3D de la PCB contemplando las entradas y salidas.
- Se tomaron en cuenta las medidas del ESP32 y los sensores de Arduino, por el momento, para solo tener que colocarlos sobre la PCB.

#### Comentarios

- Queda pendiente enseñársela al profesor para la aprobación.
- Queda pendiente definir los sensores.
- Queda pendiente definir si colocar o no los convertidores en la PCB.

## 4. Semana 4 (Semana Santa)

### 4.1. Investigación de sensores

**Fecha:** 31 de Marzo, 2026

**Horas:** De 10 a.m. a 12 m.d. (2 horas)

#### Objetivos

- Investigar sobre sensores LEM de corriente y el sensor de tensión.

#### Actividades y Resultados

- Se hace una búsqueda de sensores tipo LEM y sensores de Arduino, los cuales ya se tenían presupuestados.
- Se ven unos sensores de corriente de Arduino en el laboratorio y se guardan como posibles opciones.
- Se estudian los sensores de Arduino, ya que se ocupa que el sensor no genere mucho ruido.

#### Comentarios

- Se requiere la información de la batería para poder escoger mejor el sensor. Sin embargo, los sensores de Arduino se tienen como principal opción porque ya se tienen 2 de ellos.

## 5. Semana 5

### 5.1. Reunión con Mauricio

**Fecha:** 7 de Abril, 2026

**Horas:** De 2 p.m. a 3 p.m. (1 hora)

#### Objetivos

- Conversar sobre los avances al proyecto y planificar avances.

#### Actividades y Resultados

- Se hace una reunión en la que se conversó sobre las entradas y salidas de la PCB, el sistema de control y la batería.

#### Comentarios

- La batería sigue sin definirse, pero se tienen opciones disponibles que se pueden utilizar.
- Se comentó que el convertidor DC/DC no va a dar suficiente variación como para contemplar todos los valores de tensión de todas las opciones de batería.

### 5.2. Búsqueda de convertidor DC/DC

**Fecha:** 10 de Abril, 2026

**Horas:** De 1 p.m. a 4 p.m. (3 horas)

#### Objetivos

- Buscar el convertidor DC/DC que se tenía y verificar que dé el rango de variación de tensión para las diferentes baterías.

#### Actividades y Resultados

- Se buscó la hoja de datos del convertidor DC/DC que se había seleccionado para buscar el rango de variación.
- Al ver la hoja de datos se determinó que no tiene tanto rango de variación y que solo se pueden seleccionar valores fijos de tensión dependiendo de lo que se le meta.

#### Comentarios

- Se concluye que no se puede utilizar el convertidor DC/DC debido a que no va a funcionar. Queda pendiente decidir como equipo qué batería utilizar y posteriormente modificar la electrónica para poder utilizar diferentes baterías.

## 6. Semana 6

### 6.1. Reunión para definir la batería y conversar los avances internos

**Fecha:** 14 de Abril, 2026

**Horas:** De 1 p.m. a 3 p.m. (2 horas)

#### Objetivos

- Conversar con los compañeros de grupo sobre la batería que se va a utilizar en el prototipo inicial.

#### Actividades y Resultados

- Se hace una reunión en la universidad con los 5 miembros del grupo en la que se definió la batería de 12 V que se tiene en el Lab-Ces.
- Además, se habla de los avances en el sistema de comunicación, la PCB y la interfaz gráfica.

#### Comentarios

- Se definió la batería y se deja como tarea buscar el perfil de carga de la batería y calcular los datos para la carga y descarga para poder programar el ESP32 con los datos correctos.

### 6.2. Modificación de la PCB

**Fecha:** 17 de Abril, 2026

**Horas:** De 1 p.m. a 5 p.m. (4 horas)

#### Objetivos

- Modificar la PCB para utilizar menos área y colocar los sensores fuera de la PCB, con el objetivo de ahorrar espacio y no tener que modificar las terminales de los sensores.

#### Actividades y Resultados

- Se modifica el diseño de la PCB para reducir el espacio, colocando solo las terminales de alimentación y señal de los sensores.

#### Comentarios

- Se dejan las terminales del convertidor DC/DC, del trimmer digital y las del trimmer digital para modificarlo en un futuro si se requiere otra tensión.
- No se terminó el diseño, queda pendiente mostrar los modelos hechos al grupo y hacer las rutas en la placa.

## 7. Semana 7

### 7.1. Hacer una lista de los componentes propios de la PCB

**Fecha:** 20 de Abril, 2026

**Horas:** De 3 p.m. a 6 p.m. (3 horas)

#### Objetivos

- Hacer la lista de los componentes propios de la PCB que no se habían incluido en la lista de los materiales.

#### Actividades y Resultados

- Se toma el prototipo de PCB y se cuentan los conectores pin socket hembra, los conectores banana, los conectores tipo bloque y otros componentes.
- En una pequeña conversación con Mauricio se habla de retrasos en los pedidos de componentes y PCB, por lo que se debe pensar en soluciones alternas.

#### Comentarios

- Al tener problemas con los componentes, se deja como tarea buscar los componentes en tiendas físicas o virtuales en Costa Rica y comparar los presupuestos.
- Se deja como tarea buscar opciones diferentes a una PCB para hacer un prototipo con el que se puedan hacer pruebas.

### 7.2. Investigar sobre la soldadura en una placa perforada

**Fecha:** 22 de Abril, 2026

**Horas:** De 3 p.m. a 5 p.m. (2 horas)

#### Objetivos

- Hacer una búsqueda en YouTube y repositorios en internet donde se explica cómo soldar en una placa perforada de prototipos y cómo se utiliza.

#### Actividades y Resultados

- Se ven videos sobre la soldadura en una placa perforada y se buscan en tiendas de electrónica las placas disponibles y sus precios.

#### Comentarios

- Al ver los videos y analizarlo queda como opción disponible, pero queda comentarlo con el profesor.

## 8. Semana 8

### 8.1. Selección de la PCB dentro de los modelos propuestos

**Fecha:** 1 de Mayo, 2026

**Horas:** De 1 p.m. a 3 p.m. (2 horas)

#### Objetivos

- Seleccionar la mejor opción de PCB para presentarle al profesor Mauricio.

#### Actividades y Resultados

- Se piensa en una futura carcasa, la forma de acomodar los sensores externos y los cables que se deben conectar a la PCB, por lo que se elige la opción en la que los sensores de corriente y tensión se conectan por debajo para ahorrar espacio y que se puedan atornillar a una carcasa.

#### Comentarios

- Queda pendiente mostrarle a Mauricio la PCB para ver si le parece bien.

### 8.2. Búsqueda de los conectores que faltaban para la PCB

**Fecha:** 2 de Mayo, 2026

**Horas:** De 1 p.m. a 3 p.m. (2 horas)

#### Objetivos

- Hacer una búsqueda de los conectores tipo socket hembra que faltan y otros conectores que no se tienen en la lista.

#### Actividades y Resultados

- Se hace una búsqueda en la página de componentes electrónicos y CRcibernética, pero solo se encuentra el conector del cargador y el conector tipo bloque en el que se atornillan los cables. Los conectores tipo socket no se encontraron.

#### Comentarios

- Queda pendiente adjuntarlos en la lista, ya que solo se encontraron en Amazon.

## 9. Semana 9

### 9.1. Reunión con Mauricio para resolver dudas con la PCB

**Fecha:** 6 de Mayo, 2026

**Horas:** De 12 p.m. a 1 p.m. (1 hora)

#### Objetivos

- Conversar con el profesor sobre la PCB y una duda que surgió sobre el circuito de carga y descarga.

#### Actividades y Resultados

- Se hizo una reunión presencial con el profesor para ver el diseño de la PCB escogida. Se determinó que por tipo de conexión de la PCB el circuito de polarización inversa no es necesario, por lo que se va a quitar y se va a reordenar para poner los inductores aparte porque pueden generar ruido.
- Se hizo la consulta sobre el circuito, ya que al simularlo no se tenía muy claro si cargaba bien la batería. El profesor indicó que se debe revisar la configuración del amplificador operacional, ya que no está amplificando, y también sacar la función de transferencia desde la entrada manipulable hasta la variable controlada.
- Al tener problemas con la PCB, el profesor dijo que en lugar de hacer un prototipo en placa perforada prefiere que utilicemos un modelo de pruebas tipo hardware in the loop, con la función de transferencia de carga y descarga implementada en un microcontrolador para probar el programa y la comunicación.

#### Comentarios

- Se va a hacer el cálculo de las funciones de transferencia y la condición de carga y descarga.
- Se van a implementar las pruebas mediante un controlador C2000 para poder programarlo por medio de PLECS y evitar problemas de comunicación o programación.

### 9.2. Revisión de la simulación para revisar el rango de tensión del transistor y la amplificación

**Fecha:** 8 de Mayo, 2026

**Horas:** De 8 p.m. a 11 p.m. (3 horas)

#### Objetivos

- Revisar la simulación de PSpice que se tenía para ver si con un solo amplificador operacional se lograba amplificar lo suficiente el rango que da el ESP32.

#### Actividades y Resultados

- Se vio que con la configuración que se tenía no amplificaba nada, solo se tenía una caída de tensión.
- Se buscó la configuración usual de amplificación de los amplificadores operacionales y se realizaron los cálculos de las resistencias para lograr una ganancia en la que se tenga más tensión que el valor nominal de la batería.

#### Comentarios

- Queda pendiente probar la simulación utilizando un barrido para comprobar que sí amplifique la tensión.
- Esa simulación es preferible hacerla en un esquemático diferente para no tocar el módulo de control que se tiene en PSpice.

## 10. Semana 10

### 10.1. Simulación del circuito amplificador

**Fecha:** 13 de Mayo, 2026

**Horas:** De 2 p.m. a 6 p.m. (4 horas)

#### Objetivos

- Hacer el circuito de carga en LTspice y simularlo utilizando un barrido DC para verificar la tensión.

#### Actividades y Resultados

- Se construyó la etapa de carga del circuito utilizando una fuente de 15 V para cargar y una fuente de 12 V como batería. También se configuró el amplificador operacional para que tenga una configuración de amplificación.
- Al inicio se tuvo problemas para formar la configuración de amplificación, ya que se colocaban mal los cables y se conectaban cables a nodos que no eran. Sin embargo, luego de un tiempo se logró obtener la configuración y probar la amplificación, que llegó aproximadamente a 14 V.
- La simulación utilizada es un DC Sweep de 0 a 3.3 V en la terminal positiva del amplificador operacional, que es donde se conecta el ESP32. Este valor está en el eje X y en el eje Y se tiene el valor de amplificación.

#### Comentarios

- Como se sabe que la amplificación sí llega a un nivel alto con el circuito implementado, el próximo paso es sacar la función de transferencia para implementarla en el C2000 y comenzar las pruebas con hardware in the loop.

## 11. Semana 11

### 11.1. Cálculo de la función de transferencia

**Fecha:** 22 de Mayo, 2026

**Horas:** De 3 p.m. a 6 p.m. (3 horas)

#### Objetivos

- Calcular la función de transferencia de carga y descarga para implementarla en un microcontrolador.

#### Actividades y Resultados

- Se tomó el circuito de carga y se realizó la LTK en la malla para obtener la suma de las tensiones. Al sustituir con la ecuación del inductor y sacar la corriente se puede identificar la entrada y salida del circuito y con esto sacar la función de transferencia.

#### Comentarios

- Al obtener esta expresión se le preguntó al profesor cómo interpretarla. Él indicó que se debe poner tensión en las tensiones del denominador que se igualan a \(V_{eq}(s)\), ya que de aquí sale la condición que debe cumplir la tensión del transistor para que el circuito cargue la batería.
- En el caso del circuito de descarga se utiliza la misma expresión pero con signo negativo, ya que los circuitos son iguales y ya se había calculado la acción de control que determinó que el signo del circuito de descarga es negativo.

## 12. Semana 12

### 12.1. Simulación del circuito y sistema de control en PSpice

**Fecha:** 25 de Mayo, 2026

**Horas:** De 5 p.m. a 8 p.m. (3 horas)

#### Objetivos

- Simular el circuito actualizado con el sistema de control implementado en PSpice.

#### Actividades y Resultados

- Se modificó el circuito que ya se tenía, se calcularon de nuevo las ganancias del controlador y se simuló. Sin embargo, la simulación comenzó a dar error por convergencia en las corrientes.
- Se simplificó el circuito quitando la etapa de descarga y se volvió a simular, pero seguía dando problemas.

#### Comentarios

- La simulación no funcionó. Al cambiar la ganancia de la señal de entrada algo pasa dentro del circuito, puesto que está generando el error en el simulador.

### 12.2. Reunión con Mauricio

**Fecha:** 26 de Mayo, 2026

**Horas:** De 3 p.m. a 6 p.m. (3 horas)

#### Objetivos

- Hablar con el profesor Mauricio para preguntarle por la simulación.

#### Actividades y Resultados

- Se habló con el profesor y se estuvo tratando de simular el circuito, pero no daba resultado.
- Se encontraron inconsistencias en el circuito y en el sistema de control, como las ganancias y los modelos, por lo que el profesor indicó que se tenía que corregir.

#### Comentarios

- Queda pendiente corregir las inconsistencias en el circuito.

### 12.3. Simulación del circuito y sistema de control en PSpice parte II

**Fecha:** 28 de Mayo, 2026

**Horas:** De 5 p.m. a 8 p.m. (3 horas)

#### Objetivos

- Revisar qué está pasando en el circuito, puesto que no funciona la simulación.

#### Actividades y Resultados

- Se cambió el amplificador operacional, ya que el que se tenía no era el que se había pensado al inicio. Entonces, se importó el modelo de Texas Instruments y se simuló de nuevo.
- Al cambiar el amplificador ya corrió la simulación, pero el resultado no es muy bueno. El sistema de control no está funcionando como debería.

#### Comentarios

- Se corrigió el circuito, pero no se obtuvo el resultado esperado en la simulación, por lo que queda pendiente hablar con el profesor para buscar una solución.
- Queda pendiente hacer el cambio en la PCB, ya que se tiene que añadir la etapa de amplificación.
- El día 29 de mayo se habló rápidamente con el profesor y nos indicó que simulemos en PLECS como última opción, ya que en PSpice puede que el controlador PI en el fondo no esté realizando esa función por una cuestión matemática del simulador.

## 13. Semana 13

### 13.1. Simulación del circuito en PLECS

**Fecha:** 1 de Junio, 2026

**Horas:** De 4 p.m. a 8 p.m. (4 horas)

#### Objetivos

- Montar el circuito y el sistema de control en el simulador PLECS.

#### Actividades y Resultados

- Se construyó el circuito siguiendo las instrucciones del profesor sobre la topología del circuito y el sistema de control y se simuló en PLECS.
- El simulador dio un resultado que no se esperaba, ya que no se puede controlar la corriente. Las curvas se asemejan a lo que se quiere, pero hay picos de corriente que indican que hay algo mal en la simulación.

#### Comentarios

- Se nota que PLECS funciona mejor que PSpice, pero todavía está costando obtener la simulación bien.

### 13.2. Consulta al profesor Mauricio sobre la simulación en PLECS

**Fecha:** 2 de Junio, 2026

**Horas:** De 4 p.m. a 6 p.m. (2 horas)

#### Objetivos

- Aclarar las dudas sobre el circuito y lograr controlar la corriente con la simulación.
- Obtener un circuito para hacer las pruebas de hardware in the loop.

#### Actividades y Resultados

- Se revisó el circuito y con ayuda del profesor se identificó una fuente que no debía ir en la simulación. Al simularlo de nuevo se logró controlar la corriente bastante bien con el controlador PI.
- Se identifica que la resistencia parásita del inductor provoca problemas con la corriente del circuito aunque sea un valor muy bajo, por lo que se debe revisar la hoja de datos del inductor para obtener esa resistencia y simular con el valor correcto.

#### Comentarios

- Al revisar el inductor nos enteramos de que la corriente máxima está por debajo de la corriente que se va a utilizar, por lo que se debe buscar otro y tener especial cuidado con la corriente.
- Se va a simular con la resistencia nominal del inductor, pero a la hora de armar el circuito en placa perforada o en PCB se debe medir la resistencia del inductor con el método de 4 cables, para obtener el valor más preciso y configurar así el software del sistema.

### 13.3. Reunión virtual con los compañeros

**Fecha:** 3 de Junio, 2026

**Horas:** De 2 p.m. a 5 p.m. (3 horas)

#### Objetivos

- Comentar el avance de cada equipo de trabajo con el fin de conocer qué hace falta y coordinar las tareas pendientes.
- Ponerse de acuerdo para crear la presentación que se debe exponer en el curso de Proyecto Eléctrico el martes 9 de Junio.

#### Actividades y Resultados

- Se realizó una reunión virtual con los compañeros para ponerse al tanto del avance de cada parte del proyecto y lo que hace falta completar.
- Se consultó si algún equipo ocupaba ayuda de los demás debido a atrasos o dificultades en alguna parte del proyecto.
- Se comentó que el viernes 5 de junio del 2026 se va a realizar una reunión presencial para hacer la primera prueba hardware in the loop con el C2000 y el ESP32.

#### Comentarios

- Queda pendiente preparar la presentación del curso y realizar la primera prueba presencial.

### 13.4. Prueba hardware in the loop

**Fecha:** 5 de Junio, 2026

**Horas:** De 2 p.m. a 6 p.m. (4 horas)

#### Objetivos

- Hacer la primera prueba hardware in the loop para verificar el sistema de comunicación y la interfaz gráfica.

#### Actividades y Resultados

- Se conectó por primera vez el ESP32 con el Delfino C2000. Al C2000 se le conecta PLECS con el circuito que se simuló y al ESP32 se le configuran los datos del programa.
- Al conectarlos y cargar el programa tanto en el ESP32 como en el C2000, todo se ejecutó muy bien. Pero al momento de correrlos a la vez, con el fin de que el C2000 funcione como la planta, se comenzaron a recibir datos que no se esperaban, por lo que se debe revisar dónde está el error.

#### Comentarios

- La primera parte de la prueba funcionó correctamente, pero los datos que da la prueba son extraños, por lo que se debe revisar dónde está el fallo. Se sospecha que es en el C2000.

## 14. Semana 14

### 14.1. Pruebas hardware in the loop

**Fecha:** 9 de Junio, 2026

**Horas:** De 1 p.m. a 4 p.m. (3 horas)

#### Objetivos

- Probar el sistema de control del ESP32 con el circuito de carga de PLECS.

#### Actividades y Resultados

- Se conectó el ESP32 al C2000 con la configuración de carga, se ejecutaron los archivos y se inició la prueba.
- Se le preguntó al profesor Mauricio cómo se podían ver en tiempo real las señales de PLECS. Él mostró la forma de hacerlo con external mode y de esta forma logramos ver que el circuito sí estaba cargando.
- La interfaz gráfica mostraba ciertos problemas para conexión y para mostrar los datos.

#### Comentarios

- Se acuerda con el profesor utilizar otro C2000 para simular la batería, ya que una fuente de tensión define la tensión entre sus terminales, entonces no se puede ver un cambio en esta.
- Se anotaron las fallas de comunicación, del circuito y de la interfaz para corregirlas y probar de nuevo.

### 14.2. Correcciones en el diseño de la PCB

**Fecha:** 12 de Junio, 2026

**Horas:** De 3 p.m. a 8 p.m. (5 horas)

#### Objetivos

- Hacer las correcciones que el profesor Mauricio indicó en el prototipo de la PCB.

#### Actividades y Resultados

- Se elimina el circuito de protección de polarización inversa, ya que este no es necesario por el tipo de conexión de la alimentación.
- Se añaden los amplificadores operacionales para amplificar la señal de carga y descarga del ESP32.
- Se hace el cambio de los inductores por el modelo adecuado para la corriente que va a manejar la batería.
- Se importan los modelos 3D de los sensores y del ESP32 para mostrar la conexión de todas las partes.

#### Comentarios

- Se debe presentar la PCB al profesor para ver si ya el prototipo cumple con lo necesario para la entrega.
- Se debe actualizar el presupuesto y la lista de componentes, ya que se deben agregar amplificadores operacionales y se eliminan los componentes del circuito de protección de polarización inversa.

## 15. Semana 15

### 15.1. Implementación del modelo de batería en el hardware in the loop

**Fecha:** 18 de Junio, 2026

**Horas:** De 3 p.m. a 8 p.m. (5 horas)

#### Objetivos

- Probar el sistema implementando un modelo de batería más real para medir la tensión.

#### Actividades y Resultados

- Se conectó el ESP32 al C2000 con el circuito y a esto se le conecta el C2000 con el modelo de la batería.
- Se tienen diferentes problemas ya que no se puede visualizar el cambio de la tensión en la batería.
- Se deben hacer ajustes en la referencia de carga y el circuito, ya que el modelo de batería es de menos tensión. Sin embargo, sigue sin funcionar.
- Para este punto el circuito de PLECS ya está completo con carga y descarga, por lo que se tiene modelado el sistema completo.

#### Comentarios

- Se propone revisar y entender mejor el modelo de la batería, ya que es un poco complejo.
- Se encuentran más puntos para corregir en la aplicación, por lo que se anotan para corrección.
- Se le preguntó al profesor Mauricio sobre la PCB y mencionó que es mejor dividir la PCB en una sección de potencia y otra de electrónica, acortando las pistas de los sensores de corriente.

### 15.2. Se recopiló el avance del proyecto en el repositorio de GitHub

**Fecha:** 19 de Junio, 2026

**Horas:** De 4 p.m. a 9 p.m. (5 horas)

#### Objetivos

- Tomar las simulaciones, PCB y documentación del proyecto y subirla al repositorio junto con su respectiva explicación.

#### Actividades y Resultados

- Se subió la propuesta de diseño utilizada, las simulaciones de PLECS para comprobar que se podía controlar, los circuitos para hardware in the loop y los archivos de la PCB.
- Además, se organizó de forma que cada README esté ordenado y con las explicaciones generales de cada sección correspondiente al ciclador.

#### Comentarios

- Queda pendiente agregar los archivos de fabricación de la PCB debido a que se le debe hacer una modificación al diseño.
- Queda pendiente actualizar la última versión de la simulación hardware in the loop.

### 15.3. Corrección final de la PCB

**Fecha:** 10 de Junio, 2026

**Horas:** De 10 a.m. a 2 p.m. (4 horas)

#### Objetivos

- Corregir la PCB como el profesor indicó, generar las pistas y rellenar las capas. Además, insertar los textos que indican para qué es cada componente, incluyendo el indicador de la polaridad del conector de la alimentación.

#### Actividades y Resultados

- Se reordena en el editor 3D los componentes de la PCB considerando un sector de potencia y un sector de electrónica.
- Se conectan las pistas de la PCB considerando un ancho de pista de 1.5 mm para las secciones que manejan corrientes altas y un ancho de 0.6 mm para las pistas que conectan componentes electrónicos de baja potencia.
- Se utilizó un diseño de 4 capas con rutas solo en las capas exteriores que corresponden a la tierra.

#### Comentarios

- Con estas modificaciones queda terminada la PCB, por lo que se sube la actualización al repositorio de GitHub, su esquemático y su diseño 3D, junto con los archivos de modelos, símbolos y huellas que se utilizaron.

## 16. Semana 16

### 16.1. Implementación del modelo de batería en el hardware in the loop

**Fecha:** 23 de Junio, 2026

**Horas:** De 3 p.m. a 7 p.m. (4 horas)

#### Objetivos

- Hacer pruebas con la batería para comprobar el funcionamiento.

#### Actividades y Resultados

- Se conectó el ESP32 al C2000 con el circuito y a esto se le conecta el C2000 con el modelo de la batería.
- Se muestra un comportamiento extraño en la aplicación. En el PLECS del circuito se ven las señales donde el ESP32 indica carga y descarga, pero la corriente tiene valores muy altos y al mismo tiempo, por lo que se le atribuye a un fallo en la conexión de la batería.

#### Comentarios

- Se debe revisar la batería, que es la que está generando problemas. Además, se debe revisar el control PI en el código del microcontrolador.

### 16.2. Continuación de las pruebas

**Fecha:** 25 de Junio, 2026

**Horas:** De 3 p.m. a 8 p.m. (5 horas)

#### Objetivos

- Hacer la última prueba utilizando un modelo de batería con otro controlador para verificar que funciona.
- Definir si seguir probando la batería o continuar modelando la batería en el circuito que ya se tiene.

#### Actividades y Resultados

- Se conecta la corriente y la tensión de forma diferente, ya que se tenía la tensión directo al ESP32 como una medición. Sin embargo, el circuito la ocupa, entonces se realizaron cambios en los pines y se configuró.
- El resultado mejoró un poco porque en el circuito y en la aplicación se podía ver un comportamiento de carga y descarga, pero la batería no mostraba nada.

#### Comentarios

- Se decide descartar la idea de usar una batería con otro C2000 debido a los problemas generados y a lo complejo del modelo de la batería.

### 16.3. Continuación de las pruebas

**Fecha:** 26 de Junio, 2026

**Horas:** De 10 a.m. a 8 p.m. (10 horas)

#### Objetivos

- Hacer las pruebas necesarias para obtener el resultado de simulación que se necesita.

#### Actividades y Resultados

- Se empezó por colocar una resistencia en serie con un capacitor para simular el comportamiento de la batería.
- Luego se construyó el modelo en el C2000 y se conectó al ESP32 para iniciar las pruebas.
- Al inicio dio bastantes problemas, ya que el controlador no estaba funcionando, haciendo que la corriente tuviera un comportamiento extraño.
- Luego de ciertas modificaciones en el código del controlador PI se logró controlar la corriente y, al ejecutar el ciclado, se logró obtener el resultado esperado, donde la batería se carga y descarga controlando la corriente y viendo la tensión final de esta.

#### Comentarios

- Se dan como finalizadas las pruebas de funcionamiento de hardware in the loop, el controlador y la aplicación.|

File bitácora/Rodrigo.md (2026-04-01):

# Bitácora utilizada para controlar y tener un registro de actividades realizadas

| Documento Trabajado | Qué se hizo | Fecha |
|---|---|---|
| [`Propuesta_SW`](../propuesta/programa_sw/README.md) | Se realizan los objetivos del sistema, Usuario objetivo, Problemas que resuelve, contexto de uso, Alcances, Limitaicones, Posibles arquitecturas del sistema.  | Lunes 9 de Marzo |
| [Diaframa front end](https://share.goodnotes.com/s/2LVMFMIWfDeWFVsuXAMpBN) | Se realiza el diagrama del Front-End para el programa de Software | Martes 10 de marzo |
| Trabajo presnecial con el equipo de proyecto | Se trabajó en el diseño y análisis del circuito a realizar en PCB, así como el análisis del sistema de control por implementar | Jueves 12 de Marzo |
|Reunion con profesor encargado| Se realiza una reunion junto con el profesor encargado (Mauricio Espinoza) para poder aclarar dudas y consultas que se tienen al respecto del comportamiento del sistema. | Lunes 23 de Marzo | 
|Estudio de la utilización de WxWidgets| Se estudia sobre WxWidgets (Librería utilizada para realizar la interfaz gráfica del programa de SW) | Jueves 19 de Marzo |
|[`Uso WxWidgets en Mac`](../propuesta/programa_sw/uso_wxWidgets_mac.md)| Se realiza la integración para el uso de WxWidgets de manera fluida y permitir un flujo de trabajo más estable y llevadero | Viernes 27 de Marzo | 
|[`Propuesta final del Sistema arquitectónico y estructural del programa`](../propuesta/programa_sw/Propuesta_Arquitectura_Estructura.md.md)| Se realiza la propuesta final de la integración del sistema operativo con la descripción de la arquitectura y estructura de esta| Lunes 30 de Marzo|

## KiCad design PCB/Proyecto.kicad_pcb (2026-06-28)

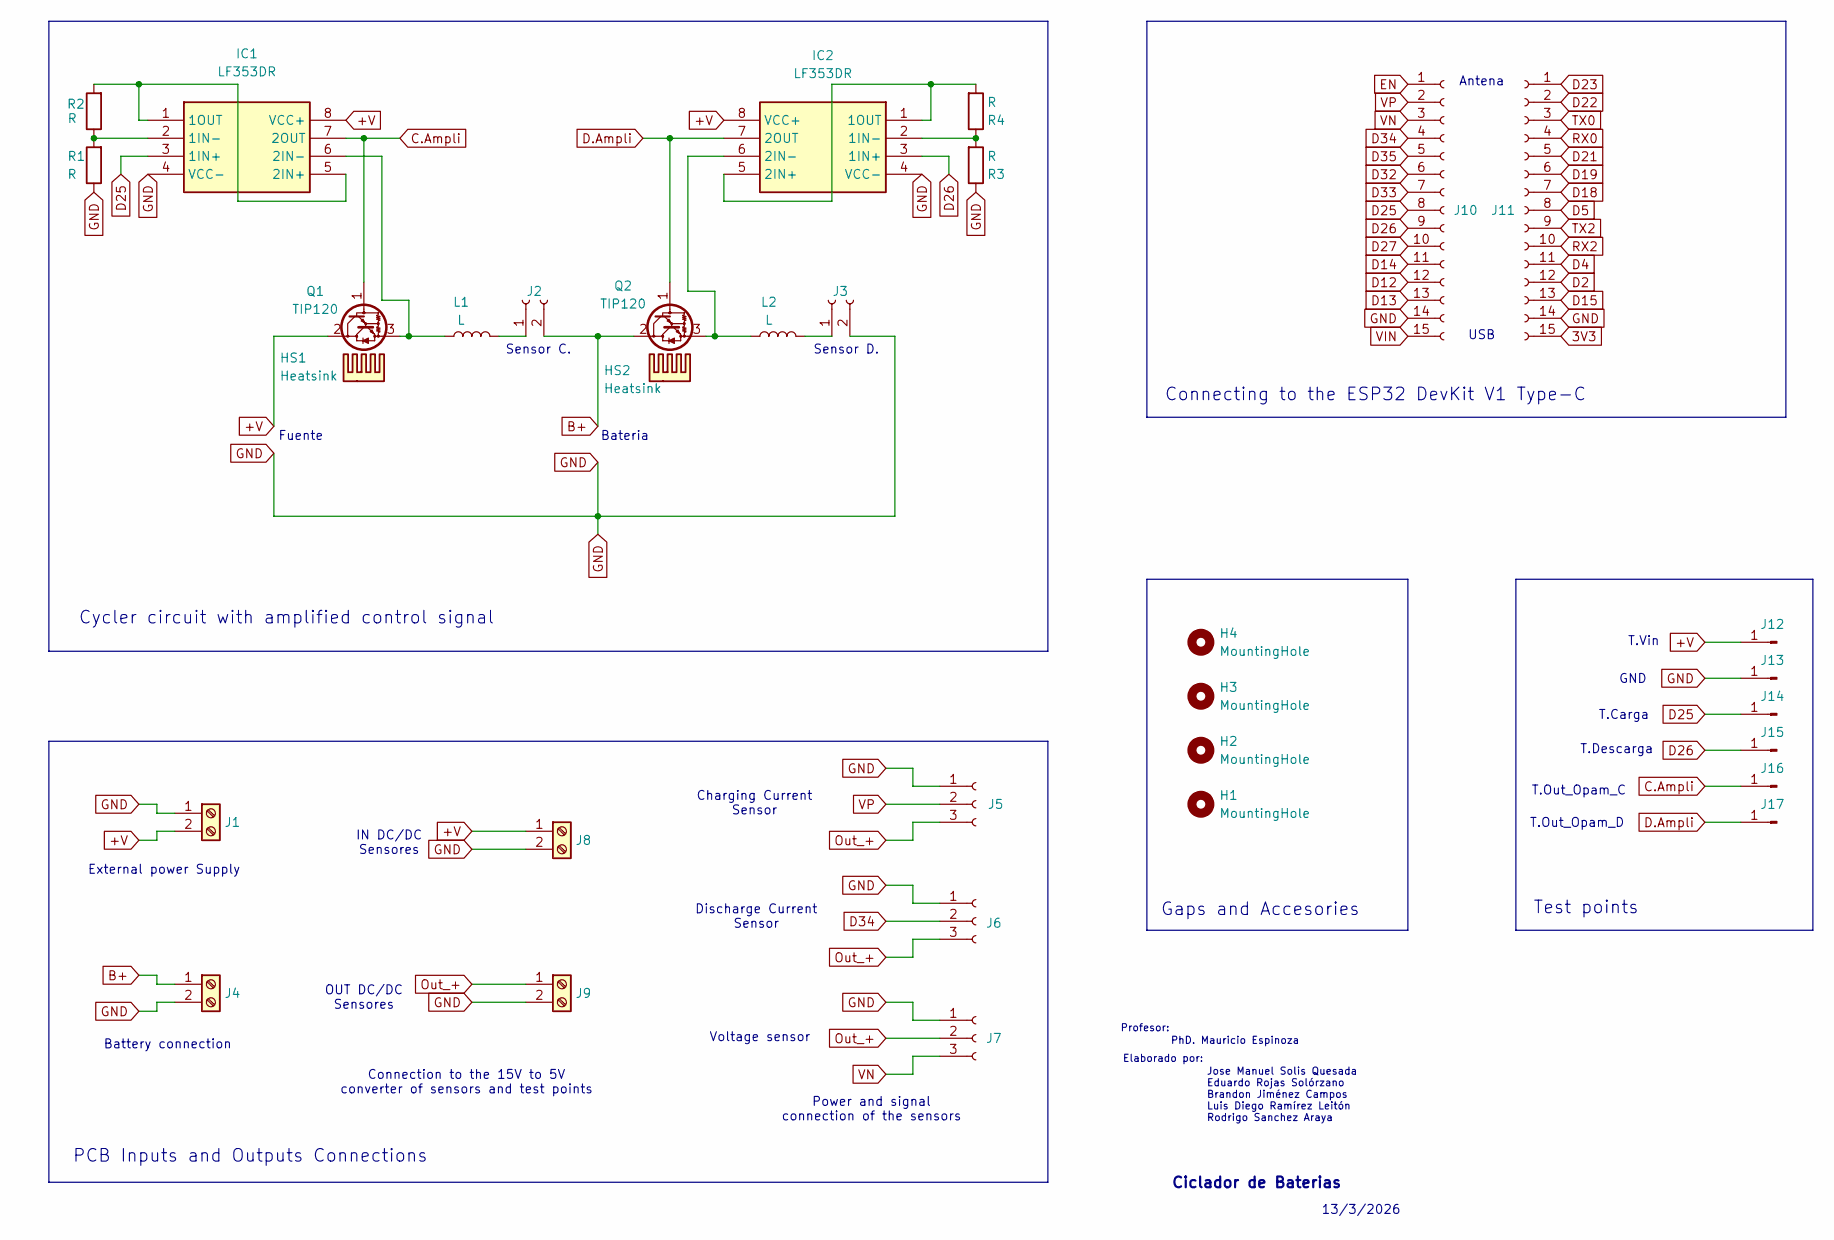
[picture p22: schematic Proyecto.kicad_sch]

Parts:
H1, H2, H3, H4: MountingHole; MountingHole_3.2mm_M3
HS1, HS2: Heatsink; Heatsink_TO220_Vert_20x15x11_Pin0
IC1, IC2: LF353DR; SOIC127P600X175-8N; Mouser Part Number 595-LF353DR
J1: Screw_Terminal_01x02; BarrelJack_GCT_DCJ200-10-A_Horizontal
J2, J3: Conn_01x02_Socket; PinSocket_1x02_P2.54mm_Vertical
J4: Screw_Terminal_01x02; TerminalBlock_Phoenix_MKDS-1,5-2_1x02_P5.00mm_Horizontal
J5, J6, J7: Conn_01x03_Socket; PinSocket_1x03_P2.54mm_Vertical
J8, J9: Screw_Terminal_01x02; TerminalBlock_Phoenix_MPT-0,5-2-2.54_1x02_P2.54mm_Horizontal
J10, J11: Conn_01x15_Socket; PinSocket_1x15_P2.54mm_Vertical
J12, J13, J14, J15, J16, J17: Conn_01x01_Pin; TestPoint_Loop_D2.54mm_Drill1.5mm_Beaded
L1, L2: L; L_Radial_D7.8mm_P5.00mm_Fastron_07HCP
Q1, Q2: TIP120; TO-220-3_Vertical
R1, R2, R3, R4: R; R_1206_3216Metric_Pad1.30x1.75mm_HandSolder

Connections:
3V3: J11.15
+V: IC1.8 (VCC+), IC2.8 (VCC+), J1.2, J8.1, J12.1, Q1.2 (C)
B+: J2.2, J4.1, Q2.2 (C)
C.Ampli: IC1.7 (2OUT), J16.1, Q1.1 (B)
D2: J11.12
D4: J11.11
D5: J11.8
D12: J10.12
D13: J10.13
D14: J10.11
D15: J11.13
D18: J11.7
D19: J11.6
D21: J11.5
D22: J11.2
D23: J11.1
D25: IC1.3 (1IN+), J10.8, J14.1
D26: IC2.3 (1IN+), J10.9, J15.1
D27: J10.10
D32: J10.6
D33: J10.7
D34: J6.2, J10.4
D35: J10.5
D.Ampli: IC2.7 (2OUT), J17.1, Q2.1 (B)
EN: J10.1
GND: IC1.4 (VCC-), IC2.4 (VCC-), J1.1, J3.2, J4.2, J5.1, J6.1, J7.1, J8.2, J9.2, J10.14, J11.14, J13.1, R1.1, R3.1
unnamed: IC1.2 (1IN-), R1.2, R2.1
unnamed: IC1.1 (1OUT), IC1.5 (2IN+), R2.2
unnamed: IC1.6 (2IN-), L1.1, Q1.3 (E)
unnamed: IC2.2 (1IN-), R3.2, R4.1
unnamed: IC2.1 (1OUT), IC2.5 (2IN+), R4.2
unnamed: IC2.6 (2IN-), L2.1, Q2.3 (E)
unnamed: J2.1, L1.2
unnamed: J3.1, L2.2
Out_+: J5.3, J6.3, J7.2, J9.1
RX0: J11.4
RX2: J11.10
TX0: J11.3
TX2: J11.9
VIN: J10.15
VN: J7.3, J10.3
VP: J5.2, J10.2

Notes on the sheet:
Jose Manuel Solis Quesada Eduardo Rojas Solórzano Brandon Jiménez Campos Luis Diego Ramírez Leitón Rodrigo Sanchez Araya
Antena
13/3/2026
Charging Current Sensor
Elaborado por:
T.Descarga
Bateria
Sensor D.
T.Out_Opam_C
Profesor:
Cycler circuit with amplified control signal
Ciclador de Baterias
IN DC/DC Sensores
Voltage sensor
Fuente
Sensor C.
GND
PhD. Mauricio Espinoza
Connecting to the ESP32 DevKit V1 Type-C
Battery connection
T.Out_Opam_D
PCB Inputs and Outputs Connections
T.Vin
Connection to the 15V to 5V converter of sensors and test points
T.Carga
Power and signal connection of the sensors
Test points
USB
Discharge Current Sensor
OUT DC/DC Sensores
Gaps and Accesories
External power Supply

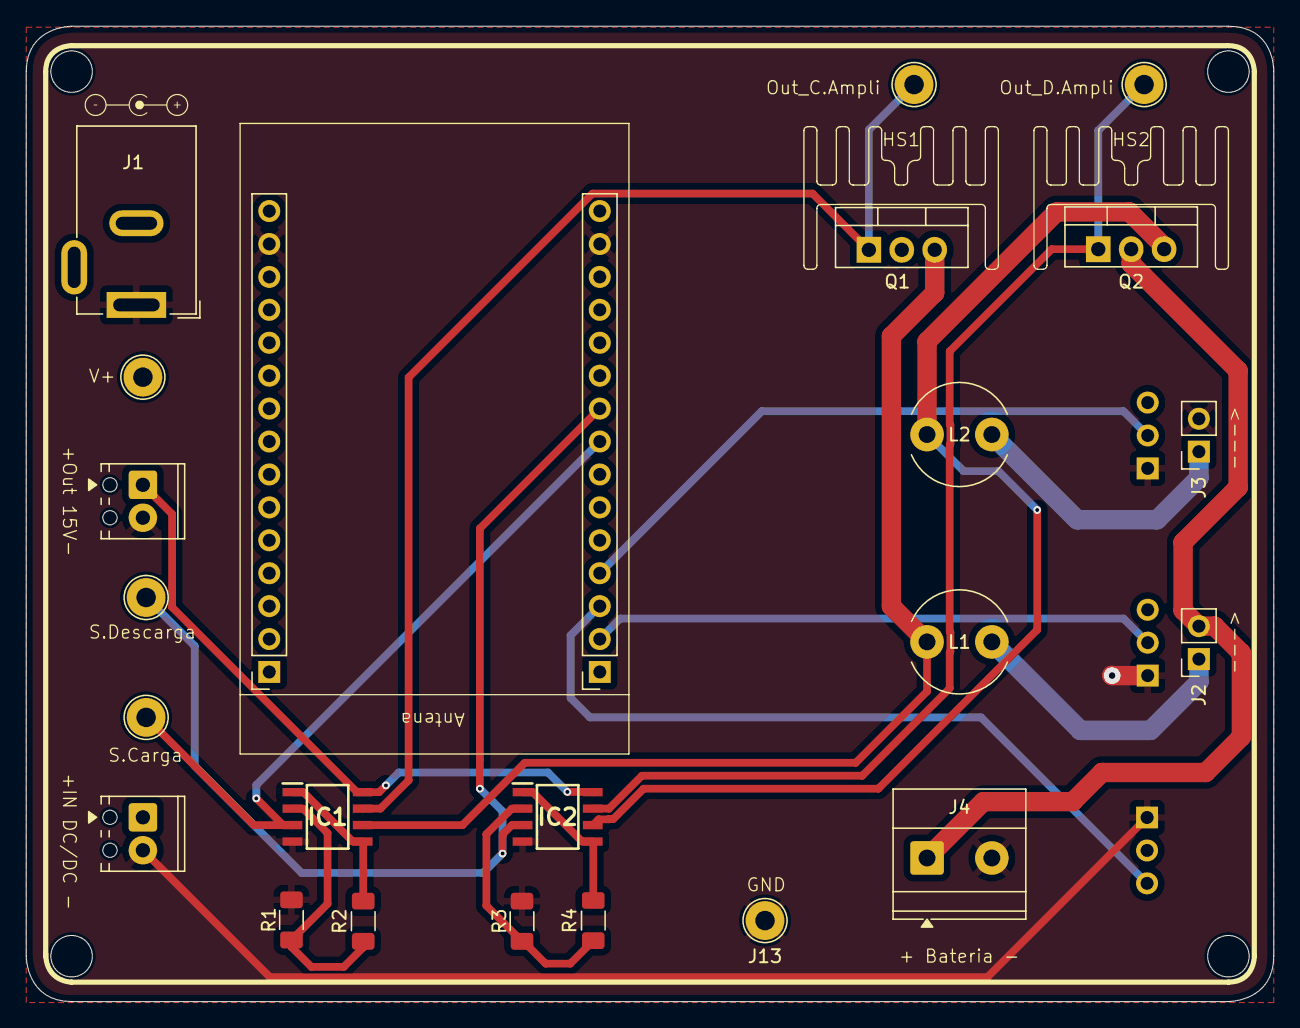
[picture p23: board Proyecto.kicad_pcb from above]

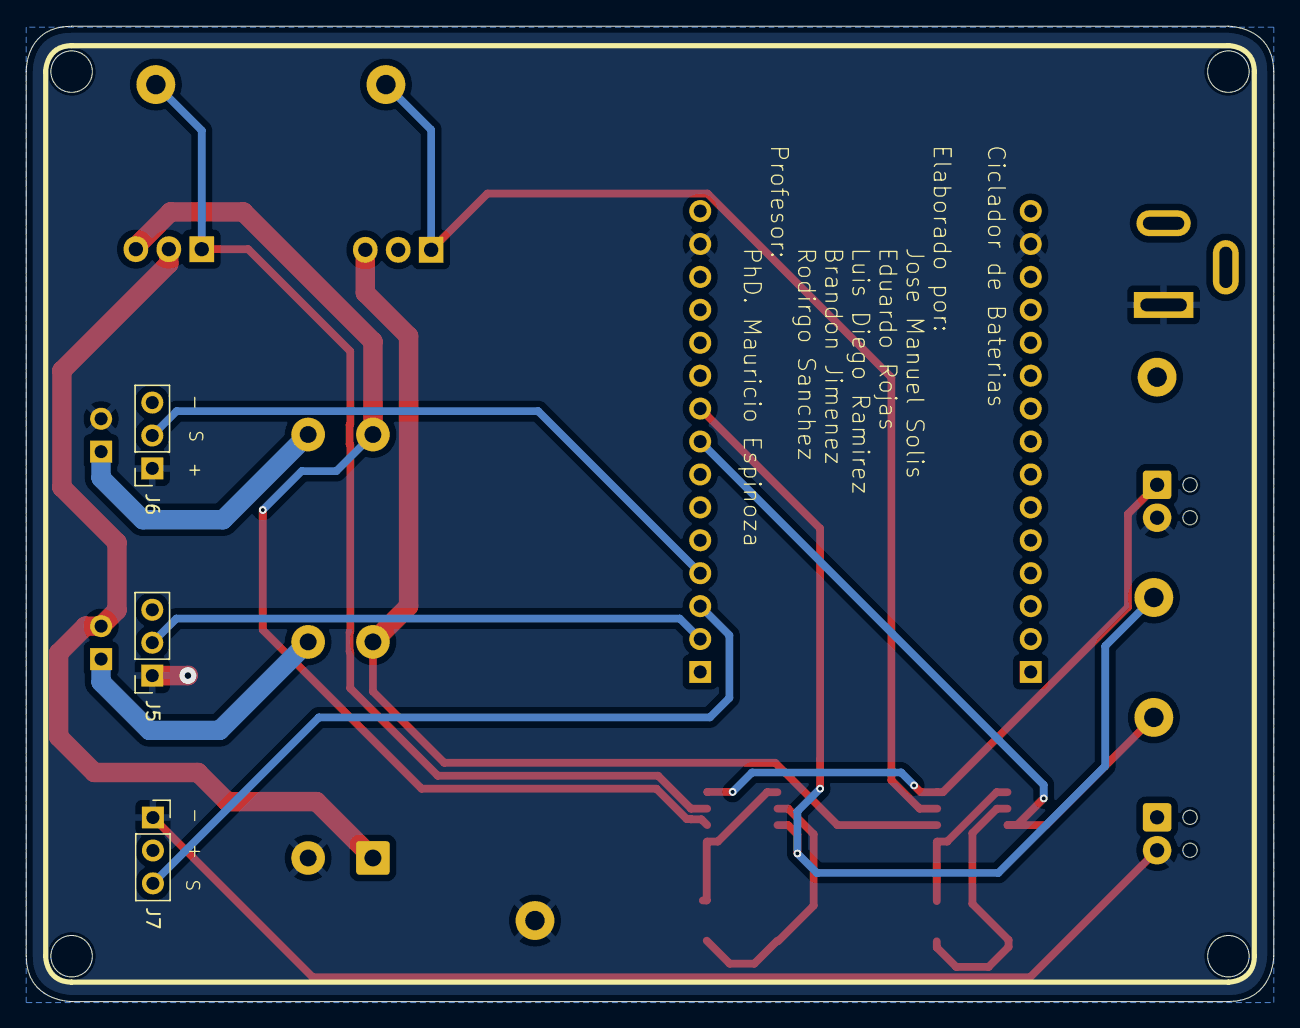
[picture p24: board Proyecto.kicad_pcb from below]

Board: 4 copper layers, 96.2 x 75.3 mm, 33 parts (3 on the bottom side), 19 nets.

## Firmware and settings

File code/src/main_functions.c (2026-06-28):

#include "main_functions.h"
#include "comm_with_pc.h"
#include "battery_controller.h"

#include <stdbool.h>
#include <stdio.h>
#include <stdlib.h>
#include <string.h>

#include "driver/uart.h"
#include "freertos/FreeRTOS.h"
#include "freertos/event_groups.h"
#include "freertos/task.h"

EventGroupHandle_t control_events = NULL;

typedef struct {
    char name[32];
    float vmax;
    float vmin;
    float amax;
    bool configured;
} battery_profile_t;

static battery_profile_t battery_profile = {0};

static bool parse_int_range(const char *text, int min, int max, int *value)
{
    char *endptr = NULL;
    long parsed = 0;

    if (text == NULL || *text == '\0') {
        return false;
    }

    parsed = strtol(text, &endptr, 10);
    if (*endptr != '\0' || parsed < min || parsed > max) {
        return false;
    }

    *value = (int)parsed;
    return true;
}

static bool parse_positive_float(const char *text, float *value)
{
    char *endptr = NULL;
    float parsed = 0.0f;

    if (text == NULL || *text == '\0') {
        return false;
    }

    parsed = strtof(text, &endptr);
    if (*endptr != '\0' || parsed <= 0.0f) {
        return false;
    }

    *value = parsed;
    return true;
}

static void send_invalid_value(uart_port_t uart_num, const char *message)
{
    enviar_datos_pc(uart_num, "#ERROR,INVALID_VALUE,");
    enviar_datos_pc(uart_num, message);
    enviar_datos_pc(uart_num, "\n");
}

void send_ack_response(uart_port_t uart_num, const char *ack)
{
    enviar_datos_pc(uart_num, ack);
    vTaskDelay(pdMS_TO_TICKS(30));
    enviar_datos_pc(uart_num, ack);
}

static void send_stop_response(uart_port_t uart_num)
{
    send_ack_response(uart_num, "#ACK,STOP\n");
}

static bool is_disconect_command(const char *text)
{
    return strstr(text, "#DISCONECT") != NULL || strstr(text, "#DISCONNECT") != NULL;
}

static void send_disconect_response(uart_port_t uart_num, const char *text)
{
    (void)text;
    send_ack_response(uart_num, "#ACK,DISCONECT\n");
}

static void poll_control_commands(uart_port_t uart_num)
{
    uint8_t buf[128];
    int len = 0;

    do {
        len = recibir_linea_pc(uart_num, buf, sizeof(buf), 1);

        if (len > 0 && strstr((char *)buf, "#STOP") != NULL) {
            EventBits_t bits = xEventGroupGetBits(control_events);

            xEventGroupSetBits(control_events, STOP_BIT);
            if (!(bits & STOP_ACK_BIT)) {
                xEventGroupSetBits(control_events, STOP_ACK_BIT);
                send_stop_response(uart_num);
            }
            xEventGroupClearBits(control_events, WORK_BIT);
        } else if (len > 0 && is_disconect_command((char *)buf)) {
            xEventGroupSetBits(control_events, STOP_BIT | STOP_ACK_BIT | DISCONECT_BIT);
            send_disconect_response(uart_num, (char *)buf);
            xEventGroupClearBits(control_events, WORK_BIT);
            memset(&battery_profile, 0, sizeof(battery_profile));
        }
    } while (len > 0);
}

static int wait_after_operation_ack(uart_port_t uart_num)
{
    const TickType_t total_delay = pdMS_TO_TICKS(150);
    const TickType_t step = pdMS_TO_TICKS(10);
    TickType_t start = xTaskGetTickCount();

    while ((xTaskGetTickCount() - start) < total_delay) {
        if (check_stop_requested(uart_num)) {
            return 1;
        }

        vTaskDelay(step);
    }

    return 0;
}

void stop_listener_task(void *pvParameters)
{
    (void)pvParameters;

    while (1) {
        vTaskDelay(pdMS_TO_TICKS(1000));
    }
}

int check_stop_requested(uart_port_t uart_num)
{
    poll_control_commands(uart_num);
    EventBits_t bits = xEventGroupGetBits(control_events);

    if (bits & STOP_BIT) {
        if (!(bits & STOP_ACK_BIT)) {
            xEventGroupSetBits(control_events, STOP_ACK_BIT);
            send_stop_response(uart_num);
        }

        xEventGroupClearBits(control_events, STOP_BIT | WORK_BIT | STOP_ACK_BIT);
        return 1;
    }

    return 0;
}

void battery_profile_function(uart_port_t uart_num, char *datos[], int count)
{
    float vmax = 0.0f;
    float vmin = 0.0f;
    float amax = 0.0f;

    if (count != 5) {
        enviar_datos_pc(uart_num, "#ERROR,INVALID_VALUE,Datos Battery incompletos\n");
        return;
    }

    if (strlen(datos[1]) == 0 || strlen(datos[1]) >= sizeof(battery_profile.name)) {
        send_invalid_value(uart_num, "Nombre de bateria invalido");
        return;
    }

    if (!parse_positive_float(datos[2], &vmax) ||
        !parse_positive_float(datos[3], &vmin) ||
        !parse_positive_float(datos[4], &amax) ||
        vmin >= vmax) {
        send_invalid_value(uart_num, "Perfil de bateria invalido");
        return;
    }

    strncpy(battery_profile.name, datos[1], sizeof(battery_profile.name) - 1);
    battery_profile.name[sizeof(battery_profile.name) - 1] = '\0';
    battery_profile.vmax = vmax;
    battery_profile.vmin = vmin;
    battery_profile.amax = amax;
    battery_profile.configured = true;

    send_ack_response(uart_num, "#ACK,Battery\n");
}

void load_function(uart_port_t uart_num, char *datos[], int count)
{
    int target_percent = 0;

    if (count != 2 || !parse_int_range(datos[1], 0, 100, &target_percent)) {
        send_invalid_value(uart_num, "Porcentaje fuera de rango");
        return;
    }

    if (!battery_profile.configured) {
        enviar_datos_pc(uart_num, "#ERROR,NOT_READY,Perfil de bateria no configurado\n");
        return;
    }

    xEventGroupClearBits(control_events, STOP_BIT | STOP_ACK_BIT);
    send_ack_response(uart_num, "#ACK,LOAD\n");
    if (wait_after_operation_ack(uart_num)) {
        return;
    }

    xEventGroupSetBits(control_events, WORK_BIT);
    int completed = battery_controller(uart_num, 25, target_percent, 0,
                                       battery_profile.vmax, battery_profile.vmin,
                                       battery_profile.amax);
    xEventGroupClearBits(control_events, WORK_BIT | STOP_BIT | STOP_ACK_BIT);
    (void)completed;
}

void unload_function(uart_port_t uart_num, char *datos[], int count)
{
    int target_percent = 0;

    if (count != 2 || !parse_int_range(datos[1], 0, 100, &target_percent)) {
        send_invalid_value(uart_num, "Porcentaje fuera de rango");
        return;
    }

    if (!battery_profile.configured) {
        enviar_datos_pc(uart_num, "#ERROR,NOT_READY,Perfil de bateria no configurado\n");
        return;
    }

    xEventGroupClearBits(control_events, STOP_BIT | STOP_ACK_BIT);
    send_ack_response(uart_num, "#ACK,UNLOAD\n");
    if (wait_after_operation_ack(uart_num)) {
        return;
    }

    xEventGroupSetBits(control_events, WORK_BIT);
    int completed = battery_controller(uart_num, 26, target_percent, 0,
                                       battery_profile.vmax, battery_profile.vmin,
                                       battery_profile.amax);
    xEventGroupClearBits(control_events, WORK_BIT | STOP_BIT | STOP_ACK_BIT);
    (void)completed;
}

void cicle_function(uart_port_t uart_num, char *datos[], int count)
{
    int mode = 0;
    int cycle_count = 0;

    if (count != 3 ||
        !parse_int_range(datos[1], 0, 1, &mode) ||
        !parse_int_range(datos[2], 0, 1000000, &cycle_count) ||
        (mode == 0 && cycle_count != 0) ||
        (mode == 1 && cycle_count <= 0)) {
        send_invalid_value(uart_num, "Parametros CICLE invalidos");
        return;
    }

    if (!battery_profile.configured) {
        enviar_datos_pc(uart_num, "#ERROR,NOT_READY,Perfil de bateria no configurado\n");
        return;
    }

    xEventGroupClearBits(control_events, STOP_BIT | STOP_ACK_BIT);
    send_ack_response(uart_num, "#ACK,CICLE\n");
    if (wait_after_operation_ack(uart_num)) {
        return;
    }

    xEventGroupSetBits(control_events, WORK_BIT);
    int completed = battery_controller(uart_num, 0, 100, mode == 0 ? -1 : cycle_count,
                                       battery_profile.vmax, battery_profile.vmin,
                                       battery_profile.amax);
    xEventGroupClearBits(control_events, WORK_BIT | STOP_BIT | STOP_ACK_BIT);
    (void)completed;
}

void stop_function(uart_port_t uart_num)
{
    EventBits_t bits = xEventGroupGetBits(control_events);

    xEventGroupSetBits(control_events, STOP_BIT | STOP_ACK_BIT);
    send_stop_response(uart_num);
    xEventGroupClearBits(control_events, WORK_BIT);

    if (!(bits & WORK_BIT)) {
        xEventGroupClearBits(control_events, STOP_BIT | STOP_ACK_BIT);
    }
}

void disconect_function(uart_port_t uart_num)
{
    xEventGroupSetBits(control_events, STOP_BIT | STOP_ACK_BIT | DISCONECT_BIT);
    xEventGroupClearBits(control_events, WORK_BIT);
    send_ack_response(uart_num, "#ACK,DISCONECT\n");
    memset(&battery_profile, 0, sizeof(battery_profile));
}

static void disconect_function_with_ack(uart_port_t uart_num, const char *command)
{
    xEventGroupSetBits(control_events, STOP_BIT | STOP_ACK_BIT | DISCONECT_BIT);
    xEventGroupClearBits(control_events, WORK_BIT);
    send_disconect_response(uart_num, command);
    memset(&battery_profile, 0, sizeof(battery_profile));
}

void process_protocol_command(uart_port_t uart_num, char *datos[], int count)
{
    if (count <= 0 || datos[0] == NULL || datos[0][0] != '#') {
        enviar_datos_pc(uart_num, "#ERROR,INVALID_FRAME,Trama invalida\n");
        return;
    }

    if (strcmp(datos[0], "#Battery") == 0) {
        battery_profile_function(uart_num, datos, count);
    } else if (strcmp(datos[0], "#LOAD") == 0) {
        load_function(uart_num, datos, count);
    } else if (strcmp(datos[0], "#UNLOAD") == 0) {
        unload_function(uart_num, datos, count);
    } else if (strcmp(datos[0], "#CICLE") == 0) {
        cicle_function(uart_num, datos, count);
    } else if (strcmp(datos[0], "#STOP") == 0) {
        if (count == 1) {
            stop_function(uart_num);
        } else {
            send_invalid_value(uart_num, "STOP no acepta parametros");
        }
    } else if (strcmp(datos[0], "#DISCONECT") == 0 || strcmp(datos[0], "#DISCONNECT") == 0) {
        if (count == 1) {
            disconect_function_with_ack(uart_num, datos[0]);
        } else {
            send_invalid_value(uart_num, "DISCONNECT no acepta parametros");
        }
    } else {
        enviar_datos_pc(uart_num, "#ERROR,INVALID_COMMAND,Comando no reconocido\n");
    }
}

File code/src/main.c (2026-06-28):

#include <stdint.h>
#include <string.h>

#include "comm_with_pc.h"
#include "driver/uart.h"
#include "esp_log.h"
#include "freertos/FreeRTOS.h"
#include "freertos/event_groups.h"
#include "freertos/task.h"
#include "hal/uart_types.h"
#include "main_functions.h"

static char *find_protocol_command(char *line)
{
    char *command = NULL;

    command = strstr(line, "#Battery");
    if (command != NULL) {
        return command;
    }

    command = strstr(line, "#LOAD");
    if (command != NULL) {
        return command;
    }

    command = strstr(line, "#UNLOAD");
    if (command != NULL) {
        return command;
    }

    command = strstr(line, "#CICLE");
    if (command != NULL) {
        return command;
    }

    return NULL;
}

static int consume_disconect_state(void)
{
    EventBits_t bits = xEventGroupGetBits(control_events);

    if (bits & DISCONECT_BIT) {
        xEventGroupClearBits(control_events, DISCONECT_BIT | STOP_BIT | STOP_ACK_BIT | WORK_BIT);
        return 1;
    }

    return 0;
}

static int process_received_line(uart_port_t uart_num, char *line, char *datos[], int conectado)
{
    char *command_start = find_protocol_command(line);

    if (strstr(line, "#DISCONECT") != NULL || strstr(line, "#DISCONNECT") != NULL) {
        int count = dividir_trama(line, datos, 8);
        process_protocol_command(uart_num, datos, count);
        return 2;
    }

    if (strstr(line, "#STOP") != NULL) {
        stop_function(uart_num);
        return 1;
    }

    if (strstr(line, "#CONNECTION") != NULL) {
        if (!conectado) {
            send_ack_response(uart_num, "#ACK,CONNECTION\n");
        }

        if (command_start == NULL) {
            return 0;
        }

        int count = dividir_trama(command_start, datos, 8);
        process_protocol_command(uart_num, datos, count);
        return 1;
    }

    if (command_start != NULL) {
        int count = dividir_trama(command_start, datos, 8);
        process_protocol_command(uart_num, datos, count);
        return 1;
    }

    if (!conectado) {
        enviar_datos_pc(uart_num, "#ERROR,NOT_READY,Conexion no establecida\n");
        return 0;
    }

    int count = dividir_trama(line, datos, 8);
    process_protocol_command(uart_num, datos, count);
    return 1;
}

static void drain_connection_burst(uart_port_t uart_num, char *datos[])
{
    uint8_t queued_line[128];
    TickType_t start = xTaskGetTickCount();

    while ((xTaskGetTickCount() - start) < pdMS_TO_TICKS(250)) {
        int length = recibir_linea_pc(uart_num, queued_line, sizeof(queued_line), 5);

        if (length <= 0) {
            vTaskDelay(pdMS_TO_TICKS(5));
            continue;
        }

        if (process_received_line(uart_num, (char *)queued_line, datos, 1)) {
            break;
        }

        memset(queued_line, 0, sizeof(queued_line));
        memset(datos, 0, sizeof(char *) * 8);
    }
}

void app_main(void)
{
    QueueHandle_t uart_queue;
    uint8_t data_receiv[128];
    char *datos[8] = {NULL};
    int conectado = 0;

    esp_log_level_set("*", ESP_LOG_NONE);
    inicializar_uart(UART_NUM_0, &uart_queue);

    control_events = xEventGroupCreate();
    configASSERT(control_events != NULL);
    xTaskCreate(stop_listener_task, "stop_listener", 2048, (void *)(intptr_t)UART_NUM_0, 5, NULL);

    while (1) {
        int length = recibir_linea_pc(UART_NUM_0, data_receiv, sizeof(data_receiv), 100);

        if (length <= 0) {
            vTaskDelay(pdMS_TO_TICKS(50));
            continue;
        }

        char *line = (char *)data_receiv;

        if (strstr(line, "#DISCONECT") != NULL || strstr(line, "#DISCONNECT") != NULL) {
            int count = dividir_trama(line, datos, 8);
            process_protocol_command(UART_NUM_0, datos, count);
            conectado = 0;
        } else if (strstr(line, "#STOP") != NULL) {
            stop_function(UART_NUM_0);
        } else if (strstr(line, "#CONNECTION") != NULL) {
            char *command_start = find_protocol_command(line);

            if (conectado) {
                if (command_start != NULL) {
                    int count = dividir_trama(command_start, datos, 8);
                    process_protocol_command(UART_NUM_0, datos, count);
                }
                memset(data_receiv, 0, sizeof(data_receiv));
                memset(datos, 0, sizeof(datos));
                vTaskDelay(pdMS_TO_TICKS(50));
                continue;
            }

            send_ack_response(UART_NUM_0, "#ACK,CONNECTION\n");

            xEventGroupClearBits(control_events, STOP_BIT | STOP_ACK_BIT | WORK_BIT);
            conectado = 1;

            if (command_start != NULL) {
                int count = dividir_trama(command_start, datos, 8);
                process_protocol_command(UART_NUM_0, datos, count);
            } else {
                drain_connection_burst(UART_NUM_0, datos);
            }
            if (consume_disconect_state()) {
                conectado = 0;
            }
        } else if (!conectado) {
            enviar_datos_pc(UART_NUM_0, "#ERROR,NOT_READY,Conexion no establecida\n");
        } else {
            char *command_start = find_protocol_command(line);
            int count = dividir_trama(command_start != NULL ? command_start : line, datos, 8);
            process_protocol_command(UART_NUM_0, datos, count);
            if (consume_disconect_state()) {
                conectado = 0;
            }
        }

        memset(data_receiv, 0, sizeof(data_receiv));
        memset(datos, 0, sizeof(datos));
        vTaskDelay(pdMS_TO_TICKS(50));
    }
}

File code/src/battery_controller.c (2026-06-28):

// Se incluyen los header files de las otras funciones realizadas:
#include "battery_controller.h"
#include "PI_controller.h"
#include "comm_with_pc.h"
#include "main_functions.h"
#include "receive.h"

// Se incluyen los archivos necesarios del ESP32:
#include "driver/dac_oneshot.h"
#include "freertos/FreeRTOS.h"
#include "freertos/task.h"
#include "esp_log.h"
#include "esp_adc/adc_oneshot.h"
#include "esp_timer.h"
#include <stdbool.h>
#include <stdio.h>

// Etiqueta que se utiliza en el logging para saber que los mensajes vienen de este módulo:
static const char *TAG = "BATTERY_CONTROLLER";

// ADC1 mapping en la devboard:
// VP/GPIO36 -> ADC_CHANNEL_0: corriente de carga
// VN/GPIO39 -> ADC_CHANNEL_3: tension de bateria
// GPIO34    -> ADC_CHANNEL_6: corriente de descarga (reservado, no usado ahora)
#define CHARGE_CURRENT_CHANNEL ADC_CHANNEL_0
#define VOLTAGE_CHANNEL ADC_CHANNEL_3
#define DISCHARGE_CURRENT_CHANNEL ADC_CHANNEL_6
#define CHARGE_DAC_CHANNEL DAC_CHAN_0
#define DISCHARGE_DAC_CHANNEL DAC_CHAN_1
#define ADC_PIN_MAX_VOLTAGE 3.3f
#define BYPASS_PI_FOR_DAC_TEST 1
#define DAC_TEST_OUTPUT 255

_Static_assert(CHARGE_DAC_CHANNEL != DISCHARGE_DAC_CHANNEL,
               "Carga y descarga deben usar DAC distintos");

// Estructura para los modos:
typedef enum {
    CARGA,
    DESCARGA,
    CICLADO,
    INVALIDO
} mode_t;

// Se implementa la función:
static float read_adc_pin_voltage(adc_channel_t channel)
{
    float value = 0.0f;
    adc_oneshot_unit_handle_t handle;

    inicializar_entradas(&handle);
    configurar_entrada(handle, channel);
    leer_datos(handle, channel, &value);
    adc_oneshot_del_unit(handle);

    return value;
}

static float read_battery_voltage(adc_channel_t channel, float battery_min_voltage,
                                  float battery_max_voltage)
{
    float pin_voltage = read_adc_pin_voltage(channel);
    float normalized_voltage = pin_voltage / ADC_PIN_MAX_VOLTAGE;

    (void)battery_min_voltage;

    if(normalized_voltage < 0.0f) {
        normalized_voltage = 0.0f;
    } else if(normalized_voltage > 1.0f) {
        normalized_voltage = 1.0f;
    }

    return normalized_voltage * battery_max_voltage;
}

static float scale_adc_to_current(adc_channel_t channel, float maximum_current)
{
    float pin_voltage = read_adc_pin_voltage(channel);
    float normalized_current = pin_voltage / ADC_PIN_MAX_VOLTAGE;

    if(normalized_current < 0.0f) {
        normalized_current = 0.0f;
    } else if(normalized_current > 1.0f) {
        normalized_current = 1.0f;
    }

    return normalized_current * maximum_current;
}

static float read_charge_current(float maximum_current)
{
    return scale_adc_to_current(CHARGE_CURRENT_CHANNEL, maximum_current);
}

static float read_discharge_current(float maximum_current)
{
    return scale_adc_to_current(DISCHARGE_CURRENT_CHANNEL, maximum_current);
}

static void activate_charge(dac_oneshot_handle_t charge_dac_handle,
                            dac_oneshot_handle_t discharge_dac_handle,
                            float reference_current)
{
    (void)reference_current;

    dac_oneshot_output_voltage(discharge_dac_handle, 0);
#if BYPASS_PI_FOR_DAC_TEST
    dac_oneshot_output_voltage(charge_dac_handle, DAC_TEST_OUTPUT);
#else
    PI_controller(charge_dac_handle, CHARGE_CURRENT_CHANNEL, reference_current);
#endif
    dac_oneshot_output_voltage(discharge_dac_handle, 0);
}

static void activate_discharge(dac_oneshot_handle_t charge_dac_handle,
                               dac_oneshot_handle_t discharge_dac_handle,
                               float reference_current)
{
    (void)reference_current;

    dac_oneshot_output_voltage(charge_dac_handle, 0);
#if BYPASS_PI_FOR_DAC_TEST
    dac_oneshot_output_voltage(discharge_dac_handle, DAC_TEST_OUTPUT);
#else
    PI_controller(discharge_dac_handle, DISCHARGE_CURRENT_CHANNEL, reference_current);
#endif
    dac_oneshot_output_voltage(charge_dac_handle, 0);
}

static void stop_outputs(dac_oneshot_handle_t charge_dac_handle,
                         dac_oneshot_handle_t discharge_dac_handle)
{
    if(charge_dac_handle != NULL) {
        dac_oneshot_output_voltage(charge_dac_handle, 0);
    }

    if(discharge_dac_handle != NULL) {
        dac_oneshot_output_voltage(discharge_dac_handle, 0);
    }
}

static void stop_charge_output(dac_oneshot_handle_t charge_dac_handle,
                               dac_oneshot_handle_t discharge_dac_handle)
{
    if(charge_dac_handle != NULL) {
        dac_oneshot_output_voltage(charge_dac_handle, 0);
    }

    if(discharge_dac_handle != NULL) {
        dac_oneshot_output_voltage(discharge_dac_handle, 0);
    }

    PI_controller_reset_channel(CHARGE_CURRENT_CHANNEL);
}

static void stop_discharge_output(dac_oneshot_handle_t charge_dac_handle,
                                  dac_oneshot_handle_t discharge_dac_handle)
{
    if(discharge_dac_handle != NULL) {
        dac_oneshot_output_voltage(discharge_dac_handle, 0);
    }

    if(charge_dac_handle != NULL) {
        dac_oneshot_output_voltage(charge_dac_handle, 0);
    }

    PI_controller_reset_channel(DISCHARGE_CURRENT_CHANNEL);
}

static void send_telemetry(uart_port_t uart_num, adc_channel_t current_channel, int state,
                           int completed_cycles, float battery_min_voltage,
                           float battery_max_voltage, float maximum_current)
{
    char message[96];
    float current = current_channel == CHARGE_CURRENT_CHANNEL ?
                    read_charge_current(maximum_current) :
                    read_discharge_current(maximum_current);
    float voltage = read_battery_voltage(VOLTAGE_CHANNEL, battery_min_voltage,
                                         battery_max_voltage);
    int64_t timestamp_ms = esp_timer_get_time() / 1000;

    snprintf(message, sizeof(message), "#DATA,%.2f,%.2f,%lld,%d,%d\n",
             voltage, current, (long long)timestamp_ms, state, completed_cycles);
    enviar_datos_pc(uart_num, message);
}
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

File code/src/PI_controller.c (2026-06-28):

#include "PI_controller.h"
#include "receive.h"

#include "esp_adc/adc_oneshot.h"
#include <stdint.h>

#define CHARGE_CURRENT_CHANNEL ADC_CHANNEL_0
#define DISCHARGE_CURRENT_CHANNEL ADC_CHANNEL_6
#define CONTROL_OUTPUT_MIN 0.0f
#define CONTROL_OUTPUT_MAX 255.0f
#define DAC_ACTIVE_MIN 216.0f
#define DAC_ACTIVE_SPAN 39.0f

static float charge_integral = 0.0f;
static float discharge_integral = 0.0f;

static float *select_integral(adc_channel_t current_channel)
{
    if (current_channel == DISCHARGE_CURRENT_CHANNEL) {
        return &discharge_integral;
    }

    return &charge_integral;
}

static uint8_t scale_control_to_dac(float control_output)
{
    float dac_output = 0.0f;

    if (control_output <= CONTROL_OUTPUT_MIN) {
        return 0;
    }

    if (control_output >= CONTROL_OUTPUT_MAX) {
        return 255;
    }

    dac_output = DAC_ACTIVE_MIN + ((DAC_ACTIVE_SPAN / CONTROL_OUTPUT_MAX) * control_output);

    if (dac_output >= 255.0f) {
        return 255;
    }

    return (uint8_t)dac_output;
}

void PI_controller_reset(void)
{
    charge_integral = 0.0f;
    discharge_integral = 0.0f;
}

void PI_controller_reset_channel(adc_channel_t current_channel)
{
    *select_integral(current_channel) = 0.0f;
}

void PI_controller(dac_oneshot_handle_t dac_handle,
                   adc_channel_t current_channel,
                   float reference_current)
{
    adc_oneshot_unit_handle_t handle;
    float measured_pin_voltage = 0.0f;
    float measured_current = 0.0f;
    float *integral = select_integral(current_channel);
    float error = 0.0f;
    float unsaturated_output = 0.0f;
    float saturated_output = 0.0f;
    float saturation_error = 0.0f;
    const float kp = 2.326e-05f;
    const float ki = 1.0000e-01f;
    const float kb = 1.0f;
    const float sample_time_s = 0.1f;
    const float sensor_gain = 10.0f;
    const float sensor_offset = 2.5f;

    if (dac_handle == NULL) {
        return;
    }

    inicializar_entradas(&handle);
    configurar_entrada(handle, current_channel);
    leer_datos(handle, current_channel, &measured_pin_voltage);
    adc_oneshot_del_unit(handle);

    measured_current = (measured_pin_voltage - sensor_offset) * sensor_gain;
    if (measured_current < 0.0f) {
        measured_current = 0.0f;
    }

    error = reference_current - measured_current;
    *integral += error * sample_time_s;

    unsaturated_output = (kp * error) + (ki * (*integral));
    saturated_output = unsaturated_output;

    if (saturated_output > CONTROL_OUTPUT_MAX) {
        saturated_output = CONTROL_OUTPUT_MAX;
    } else if (saturated_output < CONTROL_OUTPUT_MIN) {
        saturated_output = CONTROL_OUTPUT_MIN;
    }

    saturation_error = saturated_output - unsaturated_output;
    *integral += kb * saturation_error * sample_time_s;

    dac_oneshot_output_voltage(dac_handle, scale_control_to_dac(saturated_output));
}

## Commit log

2026-02-04 Added: Directorio para estipular propuesta inicial del ciclador
2026-02-04 Added: Directorio para estipular propuesta inicial del sw
2026-02-04 Added: Directorio para estipular propuesta inicial del protocolo de comunicacion hw <-> sw
2026-02-11 docs: añadir README para PCB y PLECS en ciclador
2026-02-11 docs: actualización de README para PCB y PLECS en ciclador
2026-02-17 Added: bitácora para guardar lo que se va haciendo
2026-02-17 Added: Alcances y limitaciones de la aplicación y definición de las arquitecturas para realizar dicho SW
2026-02-17 Added: Arquitectura lógica por capas para la propuesta seleccionada para realizar el SW
2026-02-21 Added: link para basar el uso de la GUI con wxWidgets
2026-03-02 Added: Cronograma en el cuál se estarán colocando las actividades esperadas a realizar semana con semana para el pryecto eléctrico
2026-03-02 Fixed: se elimina cronograma de este branch
2026-03-02 Added: cronograma para colocar objetivos a realizar por semana durante el proyecto
2026-03-03 Se agrega la tabla completa, faltan agregar los contenidos
2026-03-06 feature: Se añade el formato de la bitácora
2026-03-09 Added: Se agrega el inicio de la propuesta del protocolo de comu
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2026-03-10 Feature: Corrección en el formato de la tabla
2026-03-10 Added: Se agrega en la bitácora lo trabajado el día 10 de Marzo
2026-03-10 Added: Se agrega en la bitácora lo trabajado el día 9 de Marzo
2026-03-11 Fix: Corrección de formato de tabla y actividades
2026-03-16 Se agregan los códigos para la obtención de los datos de los sensores
2026-03-16 Added: sección de requisitos fundamentales y Envío de datos al ESP32
2026-03-17 Added: Se agregan actividades realizadas a la bitácora.
2026-03-17 Fixed: Correción del formato de la tabla la bitácora.
2026-03-17 Fixed: Correción del formato de la tabla.
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2026-03-30 Fixed: Se corriege el formato de la tabla.
2026-03-31 Added: Uso de WxWidgets para crear apliaciones, utilizando el OS de Mac
2026-04-01 Added: Se agrega propuesta final para la creación del programa de SW
2026-04-01 Added: Redirección en el README hacia el archivo de propuesta final
2026-04-01 Added: contenido realizado en las últimas semanas a la bitácora
2026-04-02 FIX: Migración a librería actualizada de ESP
    [receive.c]
2026-04-02 FIX: Se agrega un bitwidth de 12 para mayor seguridad
    [receive.c]
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2026-04-22 Added: estrucutra de la aplicación + segunda y primera capa de integración de esta, con funcionalidades cruciales para la gestión de la adquisisción de datos, la validación del protocolo, la enumerac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
2026-04-22 Se integraron los servicios de adquisición y los paneles para mostrar los resultados en tiempo real. Implementamos las gráficas de voltaje y corriente. Se vinculó el MainViewModel para coordinar la l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
2026-04-23 feat: add batView desktop app with serial control, plotting, exports, tests, and packaging
    [session_stub.csv]
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2026-04-23 Fix local packaging flow for batView
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2026-05-17 feat: Agrega archivo header que contiene la declaración de la función donde se controla la carga y descarga de la batería.
2026-05-17 feat: Agrega archivo header que contiene la declaración de la función para calcular el voltage de monitoreo.
2026-05-17 feat: Agrega archivo header que contiene la declaración de la función para monitorear la tensión de la batería.
2026-05-18 feat: Se crea la primera versión para el controlador de carga y descarga de la batería.
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2026-05-24 feat: Crea función para el cálculo de la tensión máxima de carga que se debe monitorear.
2026-05-24 feat: Crea manejo de errores en el porcentaje de carga para el cálculo máximo.
    [max_voltage.c]
2026-05-24 feat: Crea archivo de cabecera para la función del cálculo de la tensión mínima a donde se va a descargar la batería.
2026-05-24 feat: Crea archivo de la función del cálculo de la tensión mínima a donde se va a descargar la batería.
2026-05-24 fix: Corrige error de argumento en el archivo de cabecera del monitoreo.
2026-05-24 fix: Se elimina la antigua función de monitoreo para dividirla en dos (carga y descarga).
2026-05-24 feat: Crea el archivo de cabecera para la función de monitoreo en carga.
2026-05-24 feat: Crea el archivo de cabecera para la función de monitoreo en descarga.
2026-05-24 feat: Crea función correspondiente al monitoreo para el caso de carga.
2026-05-24 feat: Crea función correspondiente al monitoreo para el caso de descarga.
2026-05-26 feat: Agregan las nuevas funciones en el archvio battery_controller.c.
2026-05-28 ADD: modificación del main_functions implementando las funciones de control
2026-06-02 FIX: Arreglados algunos warnings
    [main.c]
2026-06-05 Feature: Battery added by GUI, also Fixed windows compiling error
    [session_stub.csv]
2026-06-15 Added: Propuesta del diseño del circuito y la topologia utilizada para el diseño.
2026-06-15 Fix: Corrección en nombre de la imagen del circuito.
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2026-06-15 Added: Enlace directo del readme a las diferenctes secciones del diseño del circuito.
2026-06-15 Fix: Corrección de un espacio faltante en el nombre de un enlace.
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2026-06-15 feat: Crea el header file del controlador PI.
2026-06-15 feat: Agrega soporte para los nieveles de tensión que se utilizarán.
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2026-06-15 feat: Agrega implementación del controlador PI y stop_charge en el principal de la parte de control.
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2026-06-15 feat: Crea header file de la función encargada de detener la carga.
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2026-06-16 Fix: Se corriege el formato de los titulos.
2026-06-16 Fix: Se corriege el formato de las ecuaciones que generaban error.
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2026-06-16 Added: Simulación del sistema de control en Plecs y circuito emulador de la PCB par apruebas de hardware in the loop
2026-06-18 Fix: Cambio de nombre de Diseño.md a README.md
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2026-06-18 Added: Descripción de las simulaciones implementadas en plecs para verificar el control y para hardware in the loop.
2026-06-18 Added: Se agrega el directorio con las imagenes de la explicación de las simulaciones para mostrar los resutlados
2026-06-18 Fix: Coerrección en el formato del diagrama de bloques.
2026-06-18 Fix: Coerrección de una letra en el codigo del diagrama de bloques.
2026-06-24 Fix Windows installer winget source handling
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2026-06-24 Build x64 app correctly on Windows ARM
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2026-06-25 Fix: Problems with STOP
    [main_functions.c]
2026-06-25 FIX: Problems with the ACK, connection
    [main.c]
2026-06-26 Added: Esquematico, editor de placa y archivos de fabricación de la PCB con sus repectivas dependencias de simbolos y modelos 3D utilizados para la elebarocación del prototipo.
    [7447720100.stp, 90.28.44.000.0_20191120.stp, Arduino voltage sensor v1.step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]
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2026-06-26 Fix: Corrección en la descripción de la PCB.
2026-06-27 Fix: Corrección en los diagramas de la expliciación.
2026-06-27 Fix: Corrección en el formato de los diagramas
2026-06-27 Fix: Se reduce el texto y se quietan unos diagramas.
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2026-06-28 Fixed: Se elimina todo lo relacionado a simular la bateria en un microcontrolador.
2026-06-28 FIX: New parameters kp and ki
    [PI_controller.c]
2026-06-28 FIX: Battery controller bug in cicle
    [battery_controller.c]
2026-06-28 FIX: Adapted to the new protocol betwen ESP and PC
    [comm_with_pc.c]
2026-06-28 FIX: Bugs in connection and desconnection
    [main.c]
2026-06-28 FIX: Now it uses the max and min values provided through the interface
    [main_functions.c]
2026-06-28 FIX: It uses the max value provided through the interface
    [receive.c]
2026-06-29 Fixed: Se coloca el directorio de PCB fuera de la propuesta representando un entregable.
    [7447720100.stp, 90.28.44.000.0_20191120.stp, Arduino voltage sensor v1.step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]
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
